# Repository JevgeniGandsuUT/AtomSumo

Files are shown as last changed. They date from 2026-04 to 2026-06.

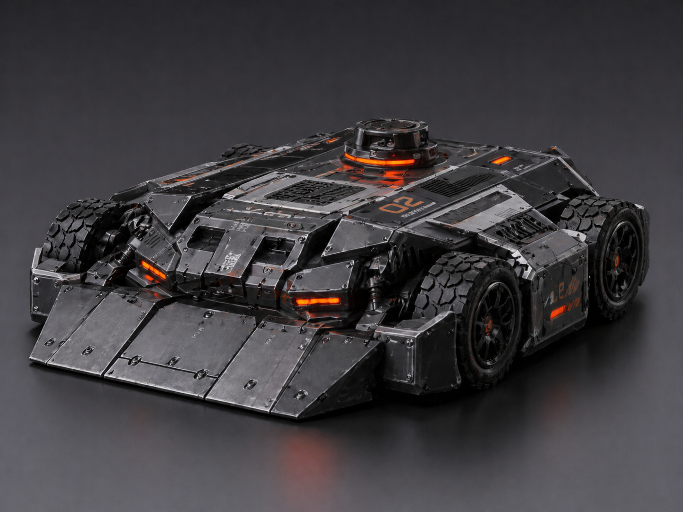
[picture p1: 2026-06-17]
hardware/cad/ver3/Concept.png

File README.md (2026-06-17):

# ATOM Sumo

`ATOM Sumo` is a SMARS-inspired sumo robot prototype for the University of Tartu prototyping course.

The project combines:
- an `M5 ATOM` main controller;
- `2 x M5 AtomS3R-CAM` camera nodes;
- `2S 18650` battery power;
- `TB6612FNG` motor driver;
- `4 x N20 6V` drive motors, wired as left/right parallel motor pairs;
- `VL53L0X` front ToF distance sensing;
- `TCS34725` floor color telemetry on Cam 2;
- a browser-based control interface over the robot's own Wi-Fi access point.

The long-term goal is one reliable working prototype plus enough documentation to support small-batch replication before the arena event.

## Current architecture

- Main controller firmware: [`firmware/main/main.ino`](firmware/main/main.ino)
- Camera firmware: [`firmware/camera/sketch_jan17a/sketch_jan17a.ino`](firmware/camera/sketch_jan17a/sketch_jan17a.ino)
- Documentation index: [`docs/README.md`](docs/README.md)
- Power concept: [`docs/specification/power_scheme.md`](docs/specification/power_scheme.md)
- Electrical block diagram: [`hardware/diagrams/power_tree.drawio`](hardware/diagrams/power_tree.drawio)
- System block diagram: [`hardware/diagrams/system_block.drawio`](hardware/diagrams/system_block.drawio)
- PCB package: [`hardware/pcb/README.md`](hardware/pcb/README.md)
- Formal V1 specification: [`docs/specification/V1_specification.md`](docs/specification/V1_specification.md)
- Requirements tracker Excel: [`docs/milestones/VERSTAPOST_REQUIREMENTS_TRACKER.xlsx`](docs/milestones/VERSTAPOST_REQUIREMENTS_TRACKER.xlsx)
- Technical comparison: [`docs/specification/TECH_COMPARISON.md`](docs/specification/TECH_COMPARISON.md)
- Estonian comparative analysis: [`docs/analysis/Vordlev_analyys.docx`](docs/analysis/Vordlev_analyys.docx), [`docs/analysis/Vordlev_analyys_summary.md`](docs/analysis/Vordlev_analyys_summary.md)
- Full test-results notebook: [`tests/notebooks/test_results_analysis.ipynb`](tests/notebooks/test_results_analysis.ipynb)
- Notebook launcher: [`tools/RUN_TEST_RESULTS_NOTEBOOK.ps1`](tools/RUN_TEST_RESULTS_NOTEBOOK.ps1)
- Original Verstapost brief images: [`docs/assets/briefs`](docs/assets/briefs)

Current hardware baseline:
- differential `4WD` drive with `2` motors wired in parallel on each side;
- `6.0V` motor rail for `4 x N20 6V` motors;
- separate `5.0V` logic rail for controller, cameras, and sensors;
- robot Wi-Fi AP `Robot-Control` with browser control UI.

Reference build components:

| Component | Quantity | Role / current status |
| --- | ---: | --- |
| `M5 ATOM` main controller | 1 | Main ESP32 controller for Wi-Fi AP, web UI, motor control, ToF, and robot state |
| `M5 AtomS3R-CAM` | 2 | Cam 1 front/operator stream and Cam 2 upward/downward diagnostic/color node |
| `VL53L0X` ToF module | 1 | Front distance sensing over I2C |
| `TCS34725` / `CJMCU-34725` RGB color sensor | 1 used / 2 ordered | Floor color telemetry on Cam 2 Grove I2C |
| `TB6612FNG` dual motor driver | 1 | Two-channel drive; left motor pair on channel A and right motor pair on channel B |
| `N20 6V` DC gearmotor | 4 | Four-wheel drive, two motors wired in parallel per side |
| Driven wheel pair `42 x 19 mm` | 2 pairs | Four driven wheels total |
| `2 x 18650` Li-Ion cells | 2 | Main `2S` battery pack |
| `2x18650` battery holder | 1 | Battery mount for the reference build |
| `2S 3A` BMS/protection board | 1 | Battery protection, still requires high-load validation |
| `1-2S` Li-Ion charger module | 1 | Charging path for the 2S pack |
| USB-C PD trigger module | 1 | Bench/charging input source used in the power setup |
| DC-DC step-down module `5A` | 2 | One set to `5.0V` logic rail, one set to `6.0V` motor rail |
| `1000uF / 16V` capacitor | 1 | Motor rail bulk decoupling near the driver |
| Slide switch | 1 | Master power switch |
| Custom PCB / interconnect board | 1 design | EasyEDA/Gerber evidence present; latest Gerber package is included |
| 3D-printed chassis/enclosure | 1 set | CAD and photo evidence present; final heat/impact/service validation still open |

## Current status

Already available in the repository:
- working main control sketch with AP mode and web control UI;
- working `AtomS3R-CAM` streaming sketch;
- V1 specification and BOM;
- power tree and PCB artifacts;
- latency, movement, ToF, and brownout measurements with executed analysis notebooks;
- CAD for the baseline chassis, functional enclosure, and real Fusion 360 robot assembly.

Important current limitation:
- final enclosure/endurance validation is still pending; the robot has movement CSVs, but heat, impact, battery-service, and repeated match-like tests still need measured tables.

## Submission tracker

The main submission document is:

- [`docs/milestones/VERSTAPOST_REQUIREMENTS_TRACKER.xlsx`](docs/milestones/VERSTAPOST_REQUIREMENTS_TRACKER.xlsx)

It lists all Verstapost 1-5 requirements in order, marks whether each item is complete, and links to the evidence files.

## Key results

HTTP control latency measurements are stored in [`tests/results`](tests/results).

Most useful current runs:
- before motor A fix: [`http_latency_2026-04-11_18-28-33.csv`](tests/results/http_latency_2026-04-11_18-28-33.csv)
- after motor A fix at `speed=0`: [`http_latency_2026-04-11_19-34-31.csv`](tests/results/http_latency_2026-04-11_19-34-31.csv)
- after fix at `speed=180`: [`http_latency_2026-04-11_19-38-18_medium_speed.csv`](tests/results/http_latency_2026-04-11_19-38-18_medium_speed.csv)

Summary:
- `speed=0` after fix: median `31.538 ms`, p95 `53.042 ms`, max `68.883 ms`
- `speed=180`: median `87.373 ms`, p95 `158.018 ms`, max `186.038 ms`

Detailed write-up:
- [`docs/testing/latency_test_result.md`](docs/testing/latency_test_result.md)
- [`tests/notebooks/http_latency_analysis.ipynb`](tests/notebooks/http_latency_analysis.ipynb)
- [`tests/notebooks/test_results_analysis.ipynb`](tests/notebooks/test_results_analysis.ipynb)

## Milestone evidence

Detailed evidence is linked from the Excel tracker and from the documentation index. The most important supporting areas are:

- [`docs/specification`](docs/specification) - specification, BOM, power scheme, and comparison analysis.
- [`docs/testing`](docs/testing) - test plan and test protocols.
- [`tests/results`](tests/results) - CSV measurement data.
- [`tests/notebooks`](tests/notebooks) - analysis notebooks.
- [`firmware`](firmware) - main controller and camera firmware.
- [`hardware`](hardware) - CAD, PCB, and diagrams.

## Repository structure

### Firmware

- [`firmware/main/`](firmware/main)  
  Main robot controller firmware: Wi-Fi AP, web UI, motor control, speed control, command handling.

- [`firmware/camera/`](firmware/camera)  
  Firmware for the `M5 AtomS3R-CAM` nodes that provide MJPEG video streams.

### Tools

- [`tools/`](tools)  
  Double-click PowerShell launchers for measurement runs and notebook regeneration.

### Documentation

- [`docs/README.md`](docs/README.md)  
  Documentation index and fastest way into the Excel tracker and evidence files.

- [`docs/specification/`](docs/specification)  
  System specification, BOM, power scheme, and technical comparison.

- [`docs/guides/`](docs/guides)  
  Assembly, flashing, and print-setting guides.

- [`docs/testing/`](docs/testing)  
  Test plan, movement/sensor protocol, and latency write-up.

- [`docs/milestones/`](docs/milestones)  
  Main Excel tracker and milestone status.

- [`docs/assets/`](docs/assets)  
  Milestone brief images, order screenshots, and photo evidence.

### Tests and measurements

- [`tests/README.md`](tests/README.md)  
  Index for executable tests, measurement CSV files, and notebooks.

- [`tests/scripts/`](tests/scripts)  
  Python scripts used to collect latency, brownout, and ToF accuracy data.

- [`tests/notebooks/`](tests/notebooks)  
  Jupyter notebooks with tables, graphs, and interpretation.

- [`tests/results/`](tests/results)  
  Raw CSV files and summary text files from executed tests.

### Electronics and diagrams

- [`hardware/diagrams/power_tree.drawio`](hardware/diagrams/power_tree.drawio)  
  Editable draw.io electrical block diagram.

- [`hardware/diagrams/system_block.drawio`](hardware/diagrams/system_block.drawio)  
  Editable top-level system architecture diagram.

- [`hardware/pcb/`](hardware/pcb)  
  PCB screenshots, schematic/layout source exports, 3D view, and Gerber archives. Start with [`hardware/pcb/README.md`](hardware/pcb/README.md).

### Mechanical

- [`hardware/cad/ver1/chassis_n20.scad`](hardware/cad/ver1/chassis_n20.scad)  
  Parametric OpenSCAD chassis model.

- [`hardware/cad/ver1/chassis_n20.stl`](hardware/cad/ver1/chassis_n20.stl)  
  Exported printable chassis geometry.

- [`hardware/cad/ver3/`](hardware/cad/ver3)  
  Functional enclosure/body models and rendered views.

- [`hardware/cad/real/`](hardware/cad/real)  
  Real Fusion 360 robot assembly and parts, including body, shell, top cover, battery pack, wheels, N20 motor reference, PCB body, and M5 Atom placement.

### Media

- [`docs/assets/photos/README.md`](docs/assets/photos/README.md)
  Photo evidence for fabrication, electronics integration, printed enclosure parts, and assembled robot state.

- [`media/video/README.md`](media/video/README.md)
  Index of video evidence with measured durations.

- [`media/video/MicrosoftTeams-video.mp4`](media/video/MicrosoftTeams-video.mp4)  
  Demo evidence showing camera streaming.

- [`media/video/0-02-05-5cafa7a371385dc5dc37026175887d8e437ea1f9ac49a73fc301792a9de68af1_9c676645fed6c17c.mp4`](media/video/0-02-05-5cafa7a371385dc5dc37026175887d8e437ea1f9ac49a73fc301792a9de68af1_9c676645fed6c17c.mp4)
  Additional robot/camera demonstration video evidence.

## Recommended reading order

If you are opening this repository for the first time, start here:

1. [`docs/specification/V1_specification.md`](docs/specification/V1_specification.md)
2. [`docs/milestones/VERSTAPOST_REQUIREMENTS_TRACKER.xlsx`](docs/milestones/VERSTAPOST_REQUIREMENTS_TRACKER.xlsx)
3. [`docs/specification/TECH_COMPARISON.md`](docs/specification/TECH_COMPARISON.md)
4. [`docs/testing/test_plan.md`](docs/testing/test_plan.md)
5. [`docs/specification/BOM.csv`](docs/specification/BOM.csv)
6. [`docs/specification/power_scheme.md`](docs/specification/power_scheme.md)
7. [`docs/testing/test_plan.md`](docs/testing/test_plan.md)
8. [`firmware/main/main.ino`](firmware/main/main.ino)
9. [`firmware/camera/sketch_jan17a/sketch_jan17a.ino`](firmware/camera/sketch_jan17a/sketch_jan17a.ino)
10. [`tests/notebooks/http_latency_analysis.ipynb`](tests/notebooks/http_latency_analysis.ipynb)

## Next project steps

Planned next technical steps:
- calibrate or explain the measured `VL53L0X` offset;
- run the full auto-behavior logger test after charging the robot;
- complete enclosure heat/impact/service/endurance tests;
- add final multi-angle assembly photos and measured validation tables.

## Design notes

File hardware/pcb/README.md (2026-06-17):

# PCB Package

This folder contains the schematic, PCB layout, 3D view, Gerber archives, and EasyEDA-style JSON source files for the ATOM Sumo interconnect board.

## Latest PCB Evidence

- [PCB_EVIDENCE_CHECK.md](PCB_EVIDENCE_CHECK.md) - current PCB evidence checklist and optional production-readiness DRC/export screenshot gap.
- [Schematic_ATOM-Sumo_2026-06-13.png](Schematic_ATOM-Sumo_2026-06-13.png) - latest schematic screenshot.
- [SCH_ATOM-Sumo_2026-06-13.json](SCH_ATOM-Sumo_2026-06-13.json) - latest schematic source export.
- [PCB_PCB_ATOM_SUMO_2026-06-13.png](PCB_PCB_ATOM_SUMO_2026-06-13.png) - latest PCB layout screenshot.
- [PCB_PCB_ATOM_SUMO_2026-06-13.json](PCB_PCB_ATOM_SUMO_2026-06-13.json) - latest PCB layout source export.
- [PCB_extra_screenshot_2026-06-13_235021.png](PCB_extra_screenshot_2026-06-13_235021.png) - additional PCB evidence screenshot.
- [3d.png](3d.png) - PCB 3D view screenshot.
- [Gerber_ATOM-Sumo_PCB_ATOM_SUMO_2026-06-17.zip](Gerber_ATOM-Sumo_PCB_ATOM_SUMO_2026-06-17.zip) - latest manufacturing Gerber/drill export.

## Previous PCB Evidence

- [Schematic_ATOM-Sumo_2026-04-11.png](Schematic_ATOM-Sumo_2026-04-11.png) - earlier schematic screenshot.
- [PCB_PCB_ATOM_SUMO_2026-04-11.png](PCB_PCB_ATOM_SUMO_2026-04-11.png) - earlier PCB layout screenshot.
- [Gerber_ATOM-Sumo_PCB_ATOM_SUMO_2026-04-08.zip](Gerber_ATOM-Sumo_PCB_ATOM_SUMO_2026-04-08.zip) - earlier Gerber package.
- [Gerber_ATOM-Sumo_PCB_ATOM_SUMO_2026-04-08-2.zip](Gerber_ATOM-Sumo_PCB_ATOM_SUMO_2026-04-08-2.zip) - source/export package.

## Submission Note

For the final milestone package, the `2026-06-13` schematic/PCB JSON/PNG files and the `2026-06-17` Gerber export are the current PCB evidence. The April files are kept as older traceability and Gerber/export history.

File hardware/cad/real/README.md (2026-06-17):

# Real CAD Package

This folder contains the real Fusion 360 CAD files for the robot mechanical package and related components.

## Main Assemblies

- [Robot.f3d](<Robot.f3d>) - robot-level Fusion design.
- [Assembly new.f3z](<Assembly new.f3z>) - packed Fusion assembly archive.
- [Rawproto.f3z](<Rawproto.f3z>) - raw prototype assembly archive.

## Robot Body Parts

- [Base 1.f3d](<Base 1.f3d>) - base body part.
- [Shell.f3d](<Shell.f3d>) - outer shell/body.
- [Topcover.f3d](<Topcover.f3d>) - top cover.
- [Battery pack.f3d](<Battery pack.f3d>) - battery pack/body integration.
- [PCB body.f3d](<PCB body.f3d>) - PCB body/holder geometry.
- [Floor.f3d](<Floor.f3d>) - arena or floor reference model.

## Drive and Hardware Parts

- [Wheel.f3d](<Wheel.f3d>) - wheel model.
- [wheel 43mm.f3d](<wheel 43mm.f3d>) - 43 mm wheel model.
- [Rear axcel.f3d](<Rear axcel.f3d>) - rear axle part.
- [N20 Reduction Gear Motor - LA002 LA003 LA004.f3d](<N20 Reduction Gear Motor - LA002 LA003 LA004.f3d>) - N20 motor model.
- [M5 ATOM Lite.f3d](<M5 ATOM Lite.f3d>) - M5 Atom controller model.

## External and Iteration Files

- [External1.f3d](<External1.f3d>)
- [External2.f3d](<External2.f3d>)
- [External3.f3d](<External3.f3d>)
- [External4.f3d](<External4.f3d>)
- [External5.f3d](<External5.f3d>)
- [3rdfloor.f3d](<3rdfloor.f3d>)
- [3D_1-PCB_PCB_ATOM_SUMO_2026-04-14.f3d](<3D_1-PCB_PCB_ATOM_SUMO_2026-04-14.f3d>)
- [a50.f3d](<a50.f3d>)
- [Cilinder.f3d](<Cilinder.f3d>)
- [Katus.f3d](<Katus.f3d>)
- [ksr_fdmtest_v4.f3d](<ksr_fdmtest_v4.f3d>)

## Submission Note

For Verstapost 4 and 5 this folder should be treated as the strongest mechanical evidence, because it contains real Fusion 360 source files for the assembled robot, body, wheels, motor reference, battery packaging, PCB holder, and controller placement.

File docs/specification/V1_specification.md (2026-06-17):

# V1 System Specification

## Document Control

| Field | Value |
| --- | --- |
| Project | SMARS-inspired Sumo Robot |
| Internal name | ATOM Sumo |
| Version | 1.0 |
| Date | 2026-04-11 |
| Status | Ready for Verstapost 1 review |
| Primary architecture | M5 ATOM main controller + 2 x M5 AtomS3R-CAM + 2S 18650 power system + 4 x N20 6V drive motors |

## 1. Purpose and Scope

This document defines the baseline system specification for a compact sumo robot intended for the University of Tartu prototyping course. The specification is written so that another team could reproduce the reference robot architecture, understand the current design decisions, and continue development through Verstapost 2-5.

The reference design standardizes on:

- an M5 ATOM controller as the robot's main brain;
- two M5 AtomS3R-CAM modules as network cameras;
- a `2S 18650` battery pack as the main energy source;
- differential 4WD drive with four N20 6V DC gearmotors, wired as two left/right parallel motor pairs;
- a browser-based operator interface over the robot's own Wi-Fi network.

This document describes the target system behavior, the current implementation baseline already present in the repository, and the required validation work still needed before full arena deployment.

## 2. Repository Baseline

The current specification is grounded in the following repository artifacts:

- [firmware/main/main.ino](../../firmware/main/main.ino)
- [firmware/camera/sketch_jan17a/sketch_jan17a.ino](../../firmware/camera/sketch_jan17a/sketch_jan17a.ino)
- [hardware/cad/ver1/chassis_n20.scad](../../hardware/cad/ver1/chassis_n20.scad)
- [hardware/cad/ver1/chassis_n20.stl](../../hardware/cad/ver1/chassis_n20.stl)
- [hardware/pcb/Gerber_ATOM-Sumo_PCB_ATOM_SUMO_2026-04-08.zip](../../hardware/pcb/Gerber_ATOM-Sumo_PCB_ATOM_SUMO_2026-04-08.zip)
- [hardware/pcb/Gerber_ATOM-Sumo_PCB_ATOM_SUMO_2026-04-08-2.zip](../../hardware/pcb/Gerber_ATOM-Sumo_PCB_ATOM_SUMO_2026-04-08-2.zip)
- [media/video/MicrosoftTeams-video.mp4](../../media/video/MicrosoftTeams-video.mp4)
- [docs/assets/briefs/Versta1.png](../assets/briefs/Versta1.png)

Observed baseline from those files:

- the main controller already creates Wi-Fi AP `Robot-Control`;
- the browser UI already supports manual drive and speed control;
- the UI already embeds two camera streams at `192.168.4.20` and `192.168.4.21`;
- the camera firmware already serves `/stream` and `/capture`;
- the CAD model already reserves space for front camera, downward camera, ToF window, PCB area, and a DC/DC converter;
- PCB Gerber and EasyEDA source files already exist.
- a recorded video artifact in `media/video/MicrosoftTeams-video.mp4` provides practical confirmation that streaming was demonstrated; the file is approximately `32 s` long.
- the original Verstapost 1 assignment/reference image is stored in `docs/assets/briefs/Versta1.png` so the repository keeps the submitted specification aligned with the course milestone brief.

## 3. System Overview

### 3.1 Mission

The robot shall operate inside a `3000 x 3000 mm` arena assembled from `1000 x 1000 mm` OSB modules with a `100 mm` hole grid, colored surface inserts, and `100 mm` high perimeter walls. The robot shall support both operator-controlled and semi-autonomous sumo behavior.

### 3.2 Top-Level Functions

The system shall:

- move using differential drive;
- stream live video to a browser UI;
- measure front obstacle distance;
- detect arena surface and boundary conditions;
- estimate robot position on the arena at least coarsely;
- accept manual drive commands and later click-to-drive commands;
- run from an onboard rechargeable `2S 18650` battery pack.

### 3.3 Selected Architecture

The selected architecture is a practical refinement of course Variant B:

- main controller: M5 ATOM module;
- front operator camera: M5 AtomS3R-CAM;
- downward arena camera: M5 AtomS3R-CAM;
- front distance sensor: `VL53L0X` ToF over `I2C`;
- motor driver: dual `TB6612FNG`;
- power system: `2S 18650` pack with charger, BMS, master switch, and separate logic and motor regulators.

This choice is based on the actual code and CAD already present in the repository.

### 3.4 Deviation from the Original Variant B Brief

The original Verstapost 1 sumo-robot brief proposes an older Android phone as the main robot brain. The reference build in this repository intentionally moves the embedded robot brain to an M5 ATOM / ESP32 controller and uses phones or laptops as browser clients only.

This deviation is acceptable for the selected prototype because it preserves the required system functions while reducing integration risk:

- the robot still provides remote operator control through a phone browser;
- the robot still has front vision through an `AtomS3R-CAM`;
- the robot still has downward sensing for floor color and future positioning;
- the robot still uses an ESP32-class controller for motor-driver interfacing;
- the control and camera firmware already exist and have been tested in the repository.

The Android-phone path remains a possible later UI/client option, but it is not required as the onboard compute platform for this reference build.

## 4. Operating Environment and Constraints

### 4.1 Arena

The robot is designed for the course arena with the following properties:

- arena size: `3000 x 3000 mm`;
- module size: `1000 x 1000 mm`;
- hole pitch: `100 mm`;
- hole diameter: `5 mm`;
- surface: OSB with removable colored inserts no higher than `2 mm` above the floor;
- wall height: `100 mm`.

### 4.2 Project Constraints

- total robot budget target: `<= 300 EUR`;
- build shall be reproducible using off-the-shelf parts plus 3D-printed parts;
- system shall be documented inside the repository;
- the V1-V2 baseline may use wheels for rapid iteration, but the motor and chassis layout shall remain compatible with a later SMARS-style tracked revision if that becomes advantageous.

### 4.3 Assumptions

- The M5 ATOM main controller and the two M5 AtomS3R-CAM boards are assumed to be available, because working firmware for them already exists in the repository.
- The exact motor gearbox ratio is not yet frozen and shall be confirmed through motor sizing and push testing, but the motor voltage class is fixed at `6V`.
- The baseline OpenSCAD CAD contains an older powerbank-style bay, while the real Fusion 360 CAD package now includes battery-pack models. The final physical tray still needs print and service-access validation.

## 5. Functional Requirements

The following functional requirements are prioritized using the `MoSCoW` method.

| ID | Requirement | Priority | Verification |
| --- | --- | --- | --- |
| FR-01 | The robot shall create its own Wi-Fi access point and allow the operator to connect without an external router. | Must | Bench test |
| FR-02 | The operator shall control the robot from a browser-based web UI running on a phone or laptop. | Must | Bench test |
| FR-03 | The web UI shall provide `forward`, `backward`, `left`, `right`, `stop`, and speed control. | Must | Bench test |
| FR-04 | The system shall provide a live front camera stream for operator vision. | Must | Bench test |
| FR-05 | The system shall provide a live downward-facing camera stream for arena observation, calibration, and positioning. | Must | Bench test |
| FR-06 | The robot shall use differential drive with two independently controlled motor channels; each channel may drive a left/right pair of parallel motors. | Must | Bench test |
| FR-07 | The robot shall measure forward obstacle distance using a `VL53L0X` ToF sensor over `I2C`. | Must | Bench test |
| FR-08 | The robot shall be powered by an onboard `2S 18650` battery pack with charging and protection circuitry. | Must | Bench test |
| FR-09 | The power system shall provide separated logic and motor supply rails with a common ground. | Must | Bench and wiring inspection |
| FR-10 | The robot shall detect arena boundary or unsafe floor state and command a stop or retreat. | Must | Arena test |
| FR-11 | The operator UI shall display basic robot state, including at minimum connection status, speed setting, and camera availability; later revisions shall add battery, ToF, and boundary state. | Should | UI test |
| FR-12 | The robot shall estimate coarse arena pose using the downward camera and arena visual features such as colored inserts, grid geometry, or fixed markers. | Should | Arena test |
| FR-13 | The operator shall be able to click a point in the front camera image and command the robot to drive toward the corresponding ground-plane target. | Should | Arena test |
| FR-14 | The robot shall support both manual mode and autonomous sumo mode. | Should | Integration test |
| FR-15 | The system should log latency, distance, and battery data during development tests. | Could | Data logging test |
| FR-16 | The system could expose a machine-readable telemetry endpoint for notebooks and automated tests. | Could | API test |
| FR-17 | The system will not depend on an Android phone as the main compute platform in this reference design. | Won't | Design review |
| FR-18 | The V1-V2 baseline will not require UWB localization hardware. | Won't | Design review |

## 6. Performance Targets

The following are target values for the reference prototype. They are engineering targets, not yet measured acceptance results.

| Parameter | Target | Notes |
| --- | --- | --- |
| Maximum body footprint | `<= 150 x 150 mm` | Current CAD body is `150 x 108 mm` |
| Minimum ground clearance | `>= 10 mm` | From CAD target |
| Nominal top speed | `0.4-0.6 m/s` | To cross the arena quickly while remaining controllable |
| 180 degree turn-in-place time | `<= 1.2 s` | At nominal `6.0V` motor rail |
| Push force at wheels | `>= 4 N` target | Final value to be validated with sled test |
| Manual command latency | median `<= 100 ms`, p95 `<= 150 ms` | Button press to observed motor response |
| Camera stream rate | `>= 10 fps` at `QVGA` | Existing camera firmware already targets streaming |
| Boot to usable control page | `<= 20 s` | Power-on to reachable web UI |
| Active runtime | `>= 15 min` or `>= 5` matches of `3 min` with reserve | Based on `2S 2500 mAh` pack |
| Boundary stop distance | `< 100 mm` worst case | Must remain inside 100 mm warning zone |
| Click-to-drive position error | `<= 150 mm` at `0.5 m`, `<= 250 mm` at `1.0 m` | Target for V3 |
| Front distance sensing range | `50 mm` to `2 m` practical target | Final practical limit depends on target material |

## 7. Mechanical Specification

### 7.1 Chassis Concept

The robot uses a compact monocoque-style 3D-printed chassis modeled in OpenSCAD.

Baseline geometry from the current CAD:

- body length: `150 mm`;
- body width: `108 mm`;
- hull height: `34 mm`;
- ground clearance target: `10 mm`;
- PCB inner area: `60.5 x 60.5 mm`;
- motor cavity designed around `N20 6V` motors;
- front wedge/scoop for pushing;
- dedicated apertures for front camera, downward camera, and ToF sensor.

### 7.2 Drive Train

The reference drive train is:

- 4 x `N20 6V` DC gearmotors (`N20` class footprint assumed by CAD);
- two-channel differential steering;
- 4 wheels total in the V1-V2 wheel baseline;
- 4 x `42 x 19 mm` wheels used as driven wheels;
- two left-side motors wired in parallel to one TB6612 channel;
- two right-side motors wired in parallel to the other TB6612 channel.

The wheel layout therefore uses:

- one left and one right driven wheel pair for propulsion and turning;
- skid/differential steering controlled by the two TB6612 channels.

The current wiring uses parallel motor pairs per side, so current draw and driver heating must be validated before high-load pushing tests.

The wheel-based baseline is acceptable for early prototyping because it accelerates testing of:

- motor selection;
- current draw;
- driver behavior;
- web control latency;
- battery performance.

The drive architecture intentionally preserves the option to replace the wheel module with SMARS-style tracks later without changing the top-level electrical or software architecture.

### 7.3 Camera and Sensor Placement

- Front camera: mounted in the front upper shell and used for operator vision and click-to-drive projection.
- Downward camera: mounted near the front underside and used for floor observation, color/boundary detection, and coarse positioning.
- ToF sensor: mounted in the front shell in a separate window offset from the front camera.

### 7.4 Battery Packaging Revision

The baseline OpenSCAD CAD still contains a `powerbank bay`. The newer real Fusion 360 CAD package includes battery-pack models, but the final physical `2S 18650` architecture shall still be validated as:

- a `2 x 18650` holder or custom printed battery tray;
- a protected and serviceable battery mount;
- easy access for cell replacement and wiring inspection;
- placement that keeps the center of mass low and near the driven axle.

## 8. Electrical Specification

### 8.1 Power Tree

The reference power tree is:

```text
USB-C PD Trigger (12 V input source during charging/setup)
    -> 1-2S Li-Ion charger module
    -> 2S 18650 pack
    -> 2S BMS / protection module
    -> master power switch
        -> Buck regulator #1 -> 5.0 V logic rail
        -> Buck regulator #2 -> 6.0 V motor rail
```

Logic rail consumers:

- M5 ATOM main controller;
- 2 x M5 AtomS3R-CAM;
- `VL53L0X`;
- future low-power sensors and status LEDs.

Motor rail consumers:

- `TB6612FNG` VM input on `6.0V` motor rail;
- left and right `N20 6V` motor pairs.

### 8.2 Power Design Requirements

- All modules shall share a common electrical ground.
- Logic and motor rails shall be separately regulated to reduce brownouts and motor noise coupling.
- A bulk capacitor of approximately `1000 uF / 16 V` shall be placed near the motor driver supply.
- The logic rail shall be fixed at `5.0V`.
- The motor rail shall be fixed at `6.0V` for the selected `N20 6V` motors.
- Raw `8.4 V` from a fully charged `2S` pack shall not be applied directly to the `N20 6V` motors.

### 8.3 Main Controller Pin Mapping

The current firmware defines the following control pins:

| Signal | Pin |
| --- | --- |
| `PWMA` | `22` |
| `AIN1` | `19` |
| `AIN2` | `23` |
| `PWMB` | `25` |
| `BIN1` | `21` |
| `BIN2` | `33` |
| `ATOM_LED_PIN` | `27` |

These pins are already used by the main controller firmware in [firmware/main/main.ino](../../firmware/main/main.ino).

### 8.4 Camera Networking

The current camera firmware uses the following network assignments:

| Device | Mode | Address |
| --- | --- | --- |
| Main controller | Wi-Fi AP | `192.168.4.1` |
| Front camera node | Wi-Fi STA | `192.168.4.20` |
| Downward camera node | Wi-Fi STA | `192.168.4.21` |

The reference SSID in current firmware is `Robot-Control`.

### 8.5 ToF Interface

The front distance sensor shall be a `VL53L0X` connected via `I2C`. Required outputs:

- filtered distance value in millimeters;
- validity or timeout status;
- update rate sufficient for obstacle avoidance and telemetry.

## 9. Software Architecture

### 9.1 Main Controller Firmware

The main controller firmware is responsible for:

- creating the robot Wi-Fi access point;
- serving the operator web UI;
- receiving manual drive commands;
- setting motor direction and PWM;
- exposing speed control;
- integrating future telemetry and sensor endpoints;
- later managing mode switching between manual and autonomous behavior.

Current implemented HTTP endpoints in the repository:

- `GET /` -> control UI;
- `GET /move?dir=forward|backward|left|right|stop`;
- `GET /speed?value=0..255`.

### 9.2 Camera Node Firmware

Each M5 AtomS3R-CAM node is responsible for:

- connecting to the main controller access point;
- serving an MJPEG stream over HTTP;
- serving single snapshot capture on request.

Current camera endpoints in the repository:

- `GET /` -> simple camera page;
- `GET /stream` -> MJPEG stream;
- `GET /capture` -> single JPEG frame.

### 9.3 Operator Web UI

The web UI shall support:

- mobile-friendly and laptop-friendly layout;
- low-friction connection to the robot AP;
- live front camera video;
- live downward camera video or diagnostic view;
- manual directional control;
- stop command;
- speed adjustment slider;
- future mode selection and state display.

### 9.4 Planned Control Modes

The software shall evolve toward the following modes:

- `Manual`: direct operator commands;
- `Click-to-drive`: operator selects a ground target in the image and the robot executes rotate-and-drive;
- `Autonomous`: robot uses ToF and arena sensing to attack and avoid leaving the arena.

## 10. Positioning and Click-to-Drive Specification

### 10.1 Positioning System

The reference design uses the downward-facing camera as the primary positioning sensor.

The downward camera shall estimate coarse robot position and floor state using one or more of:

- arena hole-grid geometry at `100 mm` spacing;
- colored arena inserts;
- fixed printed markers placed on the arena surface or perimeter.

The design intentionally keeps the exact visual marker scheme flexible so that the team can calibrate what works best in the real arena without changing the robot hardware.

### 10.2 Click-to-Drive Logic

The click-to-drive pipeline shall be:

1. The operator clicks a point in the front camera image.
2. The system maps the pixel to a camera ray using calibrated intrinsics.
3. The ray is intersected with the arena ground plane using measured camera height and mounting angle.
4. The ground-plane target is transformed into robot-local coordinates.
5. The robot first rotates toward the target, then drives forward, then stops or corrects based on ToF and floor sensing.

### 10.3 Required Calibration Data

The following values shall be measured and stored:

- front camera focal parameters or calibrated projection model;
- front camera height above ground;
- front camera pitch relative to the ground plane;
- robot center reference point used in accuracy measurements.

### 10.4 Safety Limits for Click-to-Drive

The click-to-drive controller shall reject:

- clicks outside the valid ground region of the camera image;
- targets beyond the configured maximum ground distance;
- targets that intersect known arena boundaries or walls.

## 11. Communication and Data Interface Specification

### 11.1 Network

| Parameter | Value |
| --- | --- |
| Wi-Fi mode | Main controller as AP, camera nodes as STA |
| Reference SSID | `Robot-Control` |
| Security | WPA2 PSK |
| Reference password | stored in firmware and changeable in release builds |

### 11.2 Control API

Current control API baseline:

| Endpoint | Method | Purpose |
| --- | --- | --- |
| `/` | `GET` | Serve control page |
| `/move?dir=...` | `GET` | Direction command |
| `/speed?value=...` | `GET` | Speed setting |

Target telemetry API for later revisions:

| Endpoint | Method | Purpose |
| --- | --- | --- |
| `/state` | `GET` | Return robot telemetry as JSON |
| `/mode` | `POST` or `GET` | Change manual/autonomous mode |
| `/target` | `POST` | Submit click-to-drive target |

Target `/state` JSON fields:

```json
{
  "mode": "manual",
  "speed_pwm": 180,
  "tof_mm": 235,
  "boundary": false,
  "battery_v": 7.6,
  "cam_front": true,
  "cam_down": true
}
```

## 12. Safety, Fault Handling, and Serviceability

The robot shall be designed so that:

- a stop command is always available from the UI;
- the motors default to stop on controller reset;
- the power system includes battery protection;
- camera loss does not cause uncontrolled motion;
- future revisions add command timeout or heartbeat stop behavior;
- the battery is accessible for service between matches;
- wiring is restrained against pull-out during impacts.

Known risk items that must be validated:

- the ordered `2S 3A` BMS may be too weak for motor surge current;
- the exact motor gearbox ratio is not yet frozen and must still be validated by testing;
- the final CAD battery packaging must be validated physically for `18650` service access;
- boundary/color telemetry exists, but closed-loop arena behavior is not yet completed.

## 13. Verification and Test Plan

Each functional requirement shall be verified using one or more of the following methods:

- `Bench test`: stationary electrical or software test on the workbench;
- `Drive test`: flat-floor motion test;
- `Arena test`: test inside the real or mock arena;
- `Inspection`: visual inspection of hardware or CAD;
- `Data analysis`: logged measurements analyzed in a notebook.

### 13.1 Verification Matrix

| Requirement | Planned verification |
| --- | --- |
| FR-01 | Power on the robot and confirm AP visibility and successful client connection |
| FR-02 | Open the browser UI from a phone and a laptop without installing an app |
| FR-03 | Command all directions and verify immediate motor response and stop behavior |
| FR-04 | Confirm front video stream is visible and stable for at least 2 minutes |
| FR-05 | Confirm downward camera stream is visible and aligned to the floor view |
| FR-06 | Run forward, reverse, and turn tests on a flat surface |
| FR-07 | Measure ToF readings at fixed distances such as 5, 10, 20, 30, and 50 cm |
| FR-08 | Run robot from `2S 18650` pack and confirm charging path and protected discharge path |
| FR-09 | Verify separate regulated rails and absence of controller resets during motor start/stop |
| FR-10 | Approach the arena boundary ten times and measure successful stop/retreat rate |
| FR-11 | Confirm state indicators render in the UI and update during operation |
| FR-12 | Measure coarse pose estimate against the arena grid at multiple locations |
| FR-13 | Run click-to-drive to at least five target points and measure position error |
| FR-14 | Demonstrate manual mode and autonomous mode switching |
| FR-15 | Record latency and power measurements to CSV or notebook |
| FR-16 | Query telemetry endpoint and validate field format |
| FR-17 | Design review: confirm no Android phone is required in the reference build |
| FR-18 | Design review: confirm no UWB hardware is required in the reference build |

### 13.2 Priority Acceptance Tests for V2

The most important near-term tests are:

1. Motor drive test: forward, reverse, turn, stop, current draw, and push force.
2. Wi-Fi latency test: `100+` repeated command-response measurements.
3. Camera stability test: continuous streaming over the robot AP.
4. Power test: startup, brownout resistance, and runtime using `2S 18650`.
5. ToF accuracy test: repeated measurements at known distances.

## 14. Preliminary BOM and Procurement Status

The table below reflects the currently chosen architecture for one working reference build. Where a component is not shown in the order screenshots but is clearly implied by the repository, it is marked as assumed available.

| Item | Qty | Status | Approx. cost | Notes |
| --- | --- | --- | --- | --- |
| M5 ATOM main controller | 1 | assumed available | existing stock / not counted | Working firmware already exists in repo |
| M5 AtomS3R-CAM | 2 | assumed available | existing stock / not counted | Working camera firmware already exists in repo |
| `VL53L0X` ToF module | 1 | ordered | `9.50 EUR` | Front distance sensing |
| SparkFun `TB6612FNG` dual motor driver | 1 | ordered | `13.36 EUR` | Main dual motor driver |
| USB-C PD trigger module `12 V` | 1 | ordered | `4.28 EUR` | Charging/setup source path |
| `1-2S` Li-Ion charger module | 1 | ordered | `4.28 EUR` | Charging path |
| `2x18650` battery holder | 1 | ordered | `2.38 EUR` | Needs CAD integration |
| `2S 3A` BMS/protection board | 1 | ordered | `2.85 EUR` | Must be surge-tested |
| DC/DC step-down module `5 A` | 2 | ordered | `22.80 EUR` total | One set to `5.0V` for logic, one set to `6.0V` for motors |
| Samsung `18650` `2500 mAh` `20 A` cells | 2 | ordered | `20.90 EUR` total | Main battery pack |
| `42 x 19 mm` wheels | 2 working pairs | ordered | see order history | Both wheel pairs are driven in the current 4WD build |
| `1000 uF / 16 V` capacitor | 1 | ordered | `0.929 EUR` | Motor rail decoupling |
| Slide switch | 1 | ordered | `4.83 EUR` | Master power switch |
| `TCS34725` RGB color sensor `CJMCU-34725` | 2 ordered / 1 used | ordered | `9.40 EUR` total | Cam 2 floor color telemetry; purchase evidence in `Order3.png` |
| N20 6V DC gearmotors | 4 | existing or lab stock, to be confirmed | not counted yet | Motor voltage fixed at `6V`; two motors are wired in parallel per TB6612 channel |
| 3D-printed chassis/enclosure | 1 | CAD present | material-dependent | Baseline OpenSCAD and real Fusion CAD exist; final print validation still pending |

Approximate visible reference-build BOM spend from the available order screenshots is about `110.94 EUR` in item costs, or `113.48 EUR` if the `Order3.png` sensor-shipping cost is included. This excludes any lab-stock electronics and any still-unconfirmed motor purchase.

## 15. Open Design Issues

The following issues remain open and shall be closed in later revisions:

1. Validate the final `2S 18650` mount physically for service access and impact safety.
2. Confirm gearbox ratio from calculation plus bench tests.
3. Validate whether the ordered `2S 3A` BMS and TB6612 channels can tolerate four-motor surge current.
4. Calibrate or explain the measured `VL53L0X` offset.
5. Convert downward color telemetry into closed-loop boundary/retreat behavior.
6. Calibrate click-to-drive using camera geometry or document the timed prototype limitation.

## 16. Revision Guidance for Verstapost 2

The minimum expected changes for the next revision of this specification are:

- replace remaining assumptions with measured values;
- add the exact battery holder geometry and updated chassis drawing;
- add measured motor speed, current, and push-force data;
- keep measured network latency statistics current;
- calibrate or explain measured ToF accuracy statistics;
- confirm BMS suitability under startup and stall current conditions.

## 17. Summary

This V1 specification defines a realistic and buildable sumo robot architecture that is now substantially implemented in the repository. The design is centered on an M5 ATOM controller, dual M5 AtomS3R-CAM Wi-Fi camera nodes, `2S 18650` battery power, browser-based teleoperation, ToF telemetry, Cam 2 color telemetry, and a path toward calibrated click-to-drive and arena-aware behavior.

The strongest current assets are the existing firmware, camera streaming, ToF/color telemetry, movement measurements, executed analysis notebooks, real Fusion CAD, and PCB files. The most important next steps are ToF calibration, camera-aware brownout retesting, enclosure/endurance validation, and closed-loop arena behavior.

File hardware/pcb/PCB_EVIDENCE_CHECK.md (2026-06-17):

# PCB Evidence Check

This checklist records the current PCB evidence package for the `ATOM Sumo` interconnect board.

## Available Evidence

| Evidence item | File | Status |
| --- | --- | --- |
| Latest schematic screenshot | [Schematic_ATOM-Sumo_2026-06-13.png](Schematic_ATOM-Sumo_2026-06-13.png) | available |
| Latest schematic source export | [SCH_ATOM-Sumo_2026-06-13.json](SCH_ATOM-Sumo_2026-06-13.json) | available |
| Latest PCB layout screenshot | [PCB_PCB_ATOM_SUMO_2026-06-13.png](PCB_PCB_ATOM_SUMO_2026-06-13.png) | available |
| Latest PCB layout source export | [PCB_PCB_ATOM_SUMO_2026-06-13.json](PCB_PCB_ATOM_SUMO_2026-06-13.json) | available |
| Additional PCB screenshot | [PCB_extra_screenshot_2026-06-13_235021.png](PCB_extra_screenshot_2026-06-13_235021.png) | available |
| PCB 3D view | [3d.png](3d.png) | available |
| Latest Gerber archive | [Gerber_ATOM-Sumo_PCB_ATOM_SUMO_2026-06-17.zip](Gerber_ATOM-Sumo_PCB_ATOM_SUMO_2026-06-17.zip) | current manufacturing export; contains top/bottom copper, silkscreen, paste mask, solder mask, board outline, and PTH/NPTH drill files |
| Older Gerber archive | [Gerber_ATOM-Sumo_PCB_ATOM_SUMO_2026-04-08.zip](Gerber_ATOM-Sumo_PCB_ATOM_SUMO_2026-04-08.zip) | previous export, kept for traceability |
| Extra source archive | [Gerber_ATOM-Sumo_PCB_ATOM_SUMO_2026-04-08-2.zip](Gerber_ATOM-Sumo_PCB_ATOM_SUMO_2026-04-08-2.zip) | available; contains nested EasyEDA schematic/PCB JSON export |

## Electrical Intent Covered By The Board

The PCB package supports the project wiring concept:

- M5 ATOM main controller breakout;
- TB6612FNG motor-driver wiring;
- left motor pair and right motor pair wiring;
- logic/sensor connectors;
- shared ground and separated motor/logic rails according to the documented power scheme.

Related files:

- [BOM.csv](../../docs/specification/BOM.csv)
- [power_scheme.md](../../docs/specification/power_scheme.md)
- [Schematic_ATOM-Sumo_2026-06-13.png](Schematic_ATOM-Sumo_2026-06-13.png)

## Remaining Production Evidence

The current repository has schematic/layout screenshots, source JSON, 3D PCB evidence, and the latest `2026-06-17` Gerber archive with manufacturing layers and drill files. This is sufficient for the Verstapost `PCB evidence` requirement.

For stronger production-readiness evidence, add one or both of these optional files:

- `hardware/pcb/DRC_pass_YYYY-MM-DD.png`
- `hardware/pcb/Gerber_export_confirmation_YYYY-MM-DD.png`

Recommended capture steps:

1. Open the latest PCB project in EasyEDA.
2. Run Design Rule Check.
3. Capture the result window showing no blocking errors, or record the exact warnings.
4. Export Gerber/manufacturing files.
5. Capture the export confirmation or generated archive screen.

## Current Status

The PCB package is complete enough as design/source/current-Gerber evidence for Verstapost 1-3. A dedicated DRC pass screenshot is still useful for final production confidence, but V2 `PCB evidence` can be marked complete.

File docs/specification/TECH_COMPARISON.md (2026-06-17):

# Technical Comparison and Design Rationale

This document records the main technical tradeoffs behind the `ATOM Sumo` prototype.

It supports the Verstapost 1 specification and the final Verstapost 5 handover by explaining why the current architecture was selected and what alternatives were considered.

Related Estonian comparative analysis:

- [Vordlev_analyys.docx](../analysis/Vordlev_analyys.docx)
- [Vordlev_analyys_summary.md](../analysis/Vordlev_analyys_summary.md)

## 1. Main Controller Architecture

| Option | Advantages | Disadvantages | Decision |
| --- | --- | --- | --- |
| Android phone as robot brain | camera, display, battery, high-level compute already included | harder low-level motor wiring, less reproducible mechanical integration, needs phone-specific app path | not selected |
| ESP32 / M5 ATOM main controller | simple motor control, Wi-Fi AP, Arduino workflow, compact, reproducible | less compute for heavy vision | selected |
| Raspberry Pi / Linux SBC | strong OpenCV support, easy camera processing | higher power, slower boot, more fragile power setup, heavier | not selected for current prototype |

Decision:
- The robot uses an `M5 ATOM` / ESP32 as the onboard controller.
- Phone/laptop remains the browser client, not the robot brain.

Reason:
- The repository already contains working ESP32 firmware, browser control, motor control, ToF telemetry, and camera-node integration.
- This is easier to reproduce for a course prototype than a phone-as-brain build.

Evidence:
- [main firmware](../../firmware/main/main.ino)
- [main web UI](../../firmware/main/01_WebUi.ino)

## 2. Camera Architecture

| Option | Advantages | Disadvantages | Decision |
| --- | --- | --- | --- |
| Single onboard camera | fewer parts, simpler power | cannot easily serve both operator view and downward sensing | not enough |
| Two AtomS3R-CAM nodes | separate front and downward views, independent static IPs, browser-visible streams | more Wi-Fi/power load, two boards to flash | selected |
| USB camera to SBC | good software ecosystem | requires Linux SBC and stronger power budget | not selected |

Decision:
- Use two `M5 AtomS3R-CAM` nodes:
  - Cam 1: front/operator view at `192.168.4.20`;
  - Cam 2: downward view and color sensor telemetry at `192.168.4.21`.

Reason:
- The dual-node design lets the ESP32 main controller stay focused on motor/sensor control while cameras serve video over HTTP.

Evidence:
- [camera firmware](../../firmware/camera/sketch_jan17a/sketch_jan17a.ino)
- [main web UI](../../firmware/main/01_WebUi.ino)

## 3. Drive System

| Option | Advantages | Disadvantages | Decision |
| --- | --- | --- | --- |
| Two driven wheels + passive support wheels | simple, low cost, easy to test and measure | lower pushing force with small N20 motors | considered, not final |
| Four driven wheels with two motors per side wired in parallel | better traction and roughly doubles available motor torque with the same two-channel control model | higher current per TB6612 channel, must be validated | selected |
| Tracks / SMARS-style treads | good contact area, sumo-friendly | more friction, harder mechanical sourcing, more current | possible future revision |

Decision:
- Current build uses `4WD`: two left motors are wired in parallel to one TB6612 channel, and two right motors are wired in parallel to the other TB6612 channel.

Reason:
- With small `N20 / GA12-N20` class motors, the system benefits from summing motor torque across four wheels.
- The firmware can still use differential two-channel control because the motors are grouped by side.
- Movement measurements already exist for speed, drift, turning, and ToF stop behavior.
- The tradeoff is higher channel current, so brownout and driver-heating tests are required.

This matches the separate Estonian `Vordlev analyys` document: small N20/GA12-N20 class motors are close to the motor-limited region, so adding motors can increase usable pushing force. Competition robots with much stronger motors are usually traction-limited instead, so adding more motor power does not help unless grip or mass also increases.

Evidence:
- [movement_speed_test.csv](../../tests/results/movement_speed_test.csv)
- [movement_drift_test.csv](../../tests/results/movement_drift_test.csv)
- [movement_turn_test.csv](../../tests/results/movement_turn_test.csv)

## 4. Motor Driver and Power

| Option | Advantages | Disadvantages | Decision |
| --- | --- | --- | --- |
| TB6612FNG | common, compact, supports two DC motors, good Arduino support | current margin must be checked | selected |
| L298N | common and robust-looking | inefficient, voltage drop, bulky | not selected |
| Direct transistor/MOSFET per motor | flexible | more design risk and PCB effort | not selected |

Decision:
- Use `TB6612FNG` with a regulated `6.0V` motor rail. Each output channel drives two motors in parallel.

Reason:
- The motors are treated as `N20 6V`; raw `2S` battery voltage can reach `8.4V` and should not be applied directly.
- The parallel-pair wiring keeps the control architecture simple, but current draw must be measured.

Evidence:
- [power_scheme.md](power_scheme.md)
- [BOM.csv](BOM.csv)

## 5. Battery Architecture

| Option | Advantages | Disadvantages | Decision |
| --- | --- | --- | --- |
| USB powerbank | easy bench power, integrated protection | bulky, weak motor-current story, poor enclosure fit | legacy only |
| 1S Li-Ion | simpler charging | needs boost for motors, higher current for same power | not selected |
| 2S 18650 | good energy, motor rail can be buck-regulated, common cells | needs BMS and validation | selected |

Decision:
- Use `2S 18650` with:
  - `5.0V` logic buck;
  - `6.0V` motor buck;
  - common ground;
  - BMS and master switch.

Remaining risk:
- the `2S 3A` BMS must still be checked under motor startup and stall-like load.

Evidence:
- [power_scheme.md](power_scheme.md)
- [power_tree.drawio.png](../../hardware/diagrams/power_tree.drawio.png)

## 6. Obstacle Sensing

| Option | Advantages | Disadvantages | Decision |
| --- | --- | --- | --- |
| VL53L0X ToF | direct distance in mm, simple I2C, fast enough for close obstacle logic | reflective/angle limitations, needs threshold tuning | selected |
| Camera-only obstacle detection | flexible, can detect shapes | needs calibration and vision processing | not primary |
| Ultrasonic sensor | cheap, simple | large, slower, poor for small angled surfaces | not selected |

Decision:
- Use `VL53L0X` as the front safety and obstacle sensor.

Evidence:
- [main firmware](../../firmware/main/main.ino)
- [tof_stop_test.csv](../../tests/results/tof_stop_test.csv)

Remaining work:
- fill [tof_accuracy_test.csv](../../tests/results/tof_accuracy_test.csv).

## 7. Boundary / Color Sensing

| Option | Advantages | Disadvantages | Decision |
| --- | --- | --- | --- |
| Downward camera color detection | no extra sensor, flexible | needs image processing and stable lighting | secondary/future |
| TCS34725 color sensor | direct RGB/clear values, simpler thresholds, fast polling | sees only a local spot | selected for Cam 2 |
| Reflectance sensor array | good line/boundary detection | needs extra wiring and placement | possible future improvement |

Decision:
- Add a `TCS34725` color sensor to Cam 2 Grove I2C.

Reason:
- It gives fast local color telemetry without forcing full image processing on the main controller.

Evidence:
- [camera firmware](../../firmware/camera/sketch_jan17a/sketch_jan17a.ino)
- [main web UI](../../firmware/main/01_WebUi.ino)

Remaining work:
- measure repeatability on actual arena surfaces;
- implement closed-loop retreat or marked-area behavior.

## 8. Tap-Drive / Positioning

| Option | Advantages | Disadvantages | Decision |
| --- | --- | --- | --- |
| Timed tap-drive | quick to implement, demonstrates UI workflow | not geometrically accurate | current prototype |
| Calibrated camera raycast / homography | measurable target accuracy | requires calibration images/notebook | next step |
| ArUco arena positioning | global pose awareness, strong V5 story | requires marker setup and vision processing | future work |

Decision:
- Current implementation uses timed tap-drive from camera image position.
- It is acceptable as a prototype but not as final calibrated positioning.

Evidence:
- [main web UI](../../firmware/main/01_WebUi.ino)

Remaining work:
- add calibration notebook;
- measure click-to-drive target error;
- implement ArUco or document a simpler approved alternative.

## 9. Summary

The selected architecture favors fast, reproducible integration:

- ESP32/M5 main controller for control and web UI;
- two AtomS3R-CAM nodes for video;
- VL53L0X for front distance;
- TCS34725 for downward color telemetry;
- TB6612FNG and regulated `6.0V` motor rail;
- 4WD using two parallel motor pairs on the two TB6612 channels;
- `2S 18650` battery architecture.

This is a realistic choice for a course prototype because most subsystems are already implemented and measured. The remaining work is mainly calibration, repeatability measurements, production documentation, and final autonomous arena behavior.

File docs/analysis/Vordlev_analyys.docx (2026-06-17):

Võrdlev analüüs.

1. Võrdlusobjektide kirjeldus

Robot 1 — Advanced Sumo Robot (Arduino Nano ESP32)

Advanced Sumo Robot with Arduino Nano ESP32 | Arduino Project Hub (https://projecthub.arduino.cc/moath_momani/advanced-sumo-robot-with-arduino-nano-esp32-9a2682)

Kohandatud võistlussumorobot, mis põhineb 6 harjatavaba mootoril Maxynos THOR 2318 planetaarreduktoriga — 3 mootorit kummalgi küljel. Juhtimine toimub 2 ESC kaudu (45A, kahesuunaline, üks kummalgi küljel) — 2WD arhitektuur kolmikmootoriga külje kohta. Täisautonoomne süsteem 8 IR-vastase tuvastamise anduri, 4 servaanduri ning LiPo akuga 3S 11.1V 2200mAh. Korpus trükitud 3D-printeriga.

Robot 2 — Predator Mini Sumo Robot Kit (JSumo)

Predator Mini Sumo Robot Kit (Full Kit - Not Assembled) Price Jsumo | JSumo (https://www.jsumo.com/predator-mini-sumo-robot-kit-full-kit-not-assembled)

Kommertskomplekt mini-sumo kategooria võistlusteks (kuni 500 g, 10×10 cm). CNC-freesitud alumiiniumkorpus. Mootorid: Core DC 6V 400 RPM (2 tk). Juhtplaat Genesis V.2 Arduino Nano baasil. SLT20 silikoonkattega rattad. Autonoomne süsteem. Aku LiPo 3S 11.1V 450 mAh.

Robot 3 — Tallinn ATOM

Isetehtud robot kaugjuhtimisega nutitelefoni kaudu. 4 vedavat ratast, mootorid GA12-N20 (6V, 300 RPM). Kontroller M5 ATOM koos kaameratega (M5 ATOM Cam moodulid) + laserkaugusandur VL53L0X (ToF, I2C, kuni 2m). Toide: 2× Samsung Li-Ion 18650 (2S, 7.4V nominaal) koos DC/DC step-down muunduritega (üks mootoritele ~6V, teine kontrollerile). Mitteautonoomne — operaator juhib reaalajast nutitelefonist.

2. Struktureeritud võrdlus

Parameeter | Robot 1 (Arduino ESP32) | Robot 2 (Predator JSumo) | Tallinn ATOM
Ajami tüüp | 2WD (6 mootorit, 3 külje kohta) | 2WD (2 DC mootorit) | 4WD (4 DC mootorit)
Mootori tüüp | Maxynos THOR 2318, planetaarreduktor, harjatavaba | Core DC Gear Motor, 6V, 400 RPM | GA12-N20, 6V, 300 RPM
Toide | LiPo 3S 11.1V, 2200 mAh | LiPo 3S 11.1V, 450 mAh | Li-Ion 2S 7.4V (2× 18650) + DC/DC step-down
ESC juhtimine | 45A, kahesuunaline, PWM 80 Hz | Sisseehitatud draiver Genesis V.2 | Sisseehitatud draiver (H-bridge)
Kontroller | Arduino Nano ESP32 | Genesis V.2 (Arduino Nano) | M5 ATOM
Juhtimissüsteem | Autonoomne (8 IR + 4 servaandurit) | Autonoomne (3 IR + 2 servaandurit) | Kaugjuhtimine (nutitelefon, teleoperation)
Tuvastusandurid | 8× IR + TFmini LiDAR | 3× MR45 IR | 2× M5 ATOM Cam + VL53L0X ToF (laser, kuni 2m)
Korpus | 3D-trükk (PLA/PETG) | CNC alumiinium | Isetehtud
Rattad | Maxynos High Traction 2" (51 mm) | SLT20 silikoon (33 mm) | Pololu 42×19 mm (r = 21 mm)
Piirav tegur | Traction-limited | Traction-limited | Motor-limited
Rakendusala | Võistlused (full sumo) | Võistlused (mini sumo) | Õppimisprotüüp / teleoperation

3. Pöördemomendi ja tõukejõu numbriline analüüs

Tõukejõu arvutuse valem:

F = T_total / r

kus:

- F — tõukejõud [N]
- T_total — ajami kogupöördemoment [N·m]
- r — ratta raadius [m] (võetud r = 0.02 m robotitele 1 ja 2; r = 0.021 m robotile 3, ratas 42×19 mm)

Robot 1 — Maxynos THOR 2318 (harjatavaba, planetaarreduktor)

Mootori THOR 2318 omadused planetaarreduktoriga:

- Harjatavaba mootor planetaarreduktoriga, toide 11.1V (3S LiPo)
- Hinnanguline väljundmoment reduktoril: ~0.5–1.2 N·m mootori kohta (tüüpiline vahemik selle klassi jaoks)
- 6 mootorit (3 külje kohta, 2 külge) → T_total ≈ 3.0–7.2 N·m

Jõu arvutus:

F = T_total / r = 6.0 / 0.02 = 300 N (keskmine väärtus)

Süsteem on haardepiiranguga (traction-limited): hõõrdeteguri μ ≈ 0.8 ja massi ~1 kg korral:

F_traction_max = μ × m × g = 0.8 × 1.0 × 9.81 ≈ 7.85 N

Mootorid suudavad genereerida jõudu, mis ületab haardepiirangu ~38 korda → süsteem on sügavalt traction-limited režiimis. Võimsuse suurendamine ei oma mõtet ilma roboti massi suurendamise või rehvide parandamiseta.

Robot 2 — Core DC 6V, 400 RPM (JSumo Predator)

JSumo Core mootori omadused (6V, 400 RPM):

- Tüüpiline seiskumismoment (stall torque): ~0.08–0.12 N·m mootori kohta
- Kaks mootorit → T_total ≈ 0.16–0.24 N·m

Jõu arvutus:

F = T_total / r = 0.20 / 0.02 = 10 N (keskmine)

Massi ~0.5 kg (mini sumo limiit) ja μ ≈ 0.9 (SLT20 silikoonrattad) korral:

F_traction_max = 0.9 × 0.5 × 9.81 ≈ 4.41 N

Mootorid genereerivad ~10 N, haardepiirang ~4.4 N → süsteem on samuti traction-limited, kuid väiksema varuga võrreldes robotiga 1.

Tallinn ATOM — GA12-N20, 6V, 300 RPM (4WD)

Andmed on määratud:

- Ühe mootori moment: T₁ = 0.018 N·m
- Neli mootorit → T_total = 0.072 N·m

Jõu arvutus:

F = T_total / r = 0.072 / 0.021 = 3.43 N

Õppimisprotüübi tüüpilise massi ~0.5–0.8 kg ja μ ≈ 0.6 korral:

F_traction_max = 0.6 × 0.65 × 9.81 ≈ 3.83 N

Genereeritav jõud (3.43 N) on lähedal haardepiirangule (3.83 N) → süsteem töötab motor-limited / traction-limited piiril.

Numbrilise analüüsi koondtabel

Parameeter | Robot 1 (THOR 2318) | Robot 2 (Core 400 RPM) | Tallinn ATOM
Mootoreid | 6 (3 külje kohta) | 2 | 4
T mootori kohta [N·m] | ~1.0 | ~0.10 | 0.018
T_total [N·m] | ~6.0 | ~0.20 | 0.072
F arvutuslik [N] | ~300 | ~10 | 3.43
F_traction_max [N] | ~7.85 | ~4.41 | ~3.83
Piirav tegur | Traction-limited | Traction-limited | Motor-limited
Momendi varu | ~38× | ~2× | < 1×

4. Traction-limited vs Motor-limited: kontseptuaalne erinevus

Traction-limited süsteem — mootorid genereerivad momenti, mis ületab rataste maksimaalse haardejõu pinnaga. Formaalselt:

F_motor > F_traction_max

Selles režiimis on jõudlust piiratud mitte mootori võimsus, vaid rehvi–pinna kontakti füüsika. Võimsamate mootori lisamine ei anna tõukejõu kasvu — rattad hakkavad niikuinii libisema. Parandus saavutatakse roboti massi suurendamise, rehvide materjali parandamise (silikoon > kautšuk) või kontaktpinna suurendamise kaudu.

Motor-limited süsteem — mootorid ei suuda arendada piisavat momenti haarde täieliku potentsiaali kasutamiseks:

F_motor < F_traction_max

Selles režiimis suurendab mootori lisamine või reduktori ülekandearvu suurendamine otseselt tõukejõudu. Just see on realiseeritud Tallinn ATOM prototüübis üleminekuga 2WD-lt 4WD-le.

5. Miks kasutavad võistlussumorobotid 2WD-d

Võistlusrobotid (Robot 1 ja 2) kasutavad 2WD-d järgmistel insenerlikel põhjustel:

1. Mass: võistluskategooriates on mass rangelt piiratud (mini sumo: 500 g, sumo: 3 kg). Kaks võimsat mootorit + ESC + planetaarreduktor paigutavad massi efektiivsemalt kui neli väikese võimsusega mootorit eraldi draiveritega.

2. Juhitavus: diferentsiaalajamiga 2WD tagab täpse pööramisjuhtimise (üks ratas edasi, teine tagasi = pöörlemine paigal). 4WD nõuab keerukamat juhtimissüsteemi või mehaanilist diferentsiaali.

3. Töörežiim: kõrgmomendiliste mootorite kasutamisel (Robot 1: THOR 2318, 6 mootorit) on süsteem traction-limited varuga ~38×. Mootori arvu suurendamine üle praeguse 6 ei anna tõukejõu kasvu — kõik rattad kasutavad juba kogu haardereservi. Ainus tee tõukejõu suurendamiseks on roboti massi suurendamine või rehvide materjali parandamine.

4. Töökindlus: vähem mootoreid = vähem rikkekohti, vähem elektriskeemi keerukust, vähem juhtmestiku kaalu.

6. Miks on väikese võimsusega mootoritega süsteemides otstarbekas 4WD

GA12-N20 mootoritega (T₁ = 0.018 N·m) on süsteem motor-limited. See tähendab, et:

T_2WD = 2 × 0.018 = 0.036 N·m → F = 1.71 N

T_4WD = 4 × 0.018 = 0.072 N·m → F = 3.43 N

Üleminek 2WD-lt 4WD-le kahekordistab tõukejõu ilma mootoreid vahetamata. See on otsene ja põhjendatud inseneriotsus piiratud eelarve ja komponentide kättesaadavuse tingimustes.

Lisaeelised 4WD puhul väikese võimsusega mootoritega:

- Koormuse jaotus 4 kontaktpunktile → spetsiifilise rõhu vähendamine, haarde parandamine ebatasastel pindadel
- Üksikute rataste libisemise riski vähendamine
- Platvormi stabiilsuse suurendamine kaameratega teleoperatsiooni ajal

7. Insenerlik järeldus 4WD valiku kohta Tallinn ATOM jaoks

Miks valiti 4WD

4WD valik Tallinn ATOM jaoks on tehniliselt põhjendatud otsus järgmiste piirangute tingimustes:

1. Komponentide kättesaadavus: GA12-N20 on üks levinumaid ja kättesaadavamaid mikromootoreid. T₁ = 0.018 N·m korral annab kaks mootorit F = 1.71 N — ebapiisav aktiivseks vastupanoks.
2. Motor-limited režiim: 2WD puhul ei suuda mootorid kasutada haarde täielikku reservi. 4WD viib süsteemi traction-limited lähedale (F_motor ≈ F_traction), mis on optimaalne insenerlik seisund.
3. Momendi puudujäägi kompenseerimine: 4WD kompenseerib ühe mootori madalat momenti paralleelse summeerimise kaudu:

ΔF = (T_4WD - T_2WD) / r = (0.072 - 0.036) / 0.021 = 1.71 N juurdekasv

See on 100% suurenemine ilma mootori tüüpi muutmata.

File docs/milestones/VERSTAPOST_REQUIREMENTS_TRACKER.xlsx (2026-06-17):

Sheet: Requirements
Verstapost | No. | Requirement | Done (+) | Status | Completion | Priority | Evidence 1 | Evidence 2 | Evidence 3 | Evidence 4 | Evidence 5 | Notes / remaining work
Verstapost 1 | 1 | Select and describe project concept | + | closed | Done | OK | V1_specification.md | Versta1.png |  |  |  | none
Verstapost 1 | 2 | Define architecture and main subsystems | + | closed | Done | OK | V1_specification.md | system_block.drawio.png |  |  |  | none
Verstapost 1 | 3 | Explain deviation from original Android-phone brief | + | closed | Done | OK | V1_specification.md | TECH_COMPARISON.md |  |  |  | none
Verstapost 1 | 4 | Functional requirements and priorities | + | closed | Done | OK | V1_specification.md |  |  |  |  | none
Verstapost 1 | 5 | Performance targets | + | closed | Done | OK | V1_specification.md |  |  |  |  | later compare with final tests
Verstapost 1 | 6 | BOM with procurement status | + | closed | Done | OK | BOM.csv | Order1.png | Order2.png |  |  | final release BOM still needs exact sources for all actual build parts
Verstapost 1 | 7 | Power architecture | + | closed | Done | OK | power_scheme.md | power_tree.drawio.png | power_brownout_test.csv |  |  | direct current measurement and camera-aware brownout retest still needed
Verstapost 1 | 8 | Testing plan | + | closed | Done | OK | test_plan.md |  |  |  |  | keep updated as measurements are added
Verstapost 1 | 9 | Design evidence | + | closed | Done | OK | hardware/cad/ver1 | hardware/pcb/README.md | main | cam |  | none for V1
Verstapost 1 | 10 | Comparative/tradeoff analysis | + | closed | Done | OK | TECH_COMPARISON.md | Vordlev_analyys_summary.md | Vordlev_analyys.docx |  |  | update if the architecture changes
Verstapost 2 | 1 | Demonstrate control chain from browser to motors | + | closed | Done | OK | main firmware | web UI | motion logic |  |  | none
Verstapost 2 | 2 | Robot Wi-Fi AP and web server | + | closed | Done | OK | main firmware | web handlers |  |  |  | none
Verstapost 2 | 3 | Manual movement commands | + | closed | Done | OK | main UI | movement_speed_test.csv |  |  |  | motor trim can be improved
Verstapost 2 | 4 | Speed/drift/turn measurements | + | closed | Done | OK | movement_speed_test.csv | movement_drift_test.csv | movement_turn_test.csv | tof_stop_test.csv |  | none
Verstapost 2 | 5 | HTTP latency measurement | + | closed | Done | OK | http_latency_analysis.ipynb | latency_test_result.md | test_results_analysis.ipynb |  |  | update after new latency runs
Verstapost 2 | 6 | Camera stream evidence | + | closed | Done | OK | camera firmware | demo video |  |  |  | add newer demo video if available
Verstapost 2 | 7 | ToF integration | + | closed | Done | OK | main firmware | tof_stop_test.csv | tof_accuracy_test.csv | tof_accuracy_collect.py | ToF calibration note | Offset measured and documented; correction model valid for 50-300 mm short/medium obstacle logic; retest after final mounting.
Verstapost 2 | 8 | PCB evidence | + | closed | Complete | Done | hardware/pcb/README.md | PCB evidence check |  |  | Latest Gerber/drill archive 2026-06-17 | Closed: schematic/layout PNG+JSON, 3D PCB screenshot, and latest 2026-06-17 Gerber/drill manufacturing archive are present. DRC screenshot remains optional production evidence.
Verstapost 2 | 9 | Power robustness | + | closed | Complete | Done | power_brownout_test.csv | power_brownout_test.py | Power brownout analysis | Power brownout retest 2026-06-17 | Power brownout retest summary | Closed for documented operating range PWM 80-180: final retest has 30/30 rows with reset=no and Wi-Fi disconnect=no; browser camera observed during test. PWM 255 is documented as outside stable operating range.
Verstapost 3 | 1 | Integrate motors, cameras, sensors, and UI | + | closed | Done | OK | main UI | main | cam |  |  | none for integration claim
Verstapost 3 | 2 | Show both camera streams in operator UI | + | closed | Done | OK | main UI |  |  |  |  | add current demo video if possible
Verstapost 3 | 3 | Front ToF telemetry in UI | + | closed | Done | OK | main UI | web handlers | tof_accuracy_test.csv |  |  | calibrate or explain measured offset
Verstapost 3 | 4 | Downward color telemetry | + | closed | Done | OK | camera firmware | main UI |  |  |  | color repeatability rows
Verstapost 3 | 5 | Click/tap-to-drive | + | closed | Complete | Done | main UI | Tap-drive algorithm | Camera calibration and tap-drive plan | Tap-drive accuracy template | Tap-drive accuracy summary | Closed: timed tap-drive algorithm measured in 5 physical trials; 5/5 pass, median error 20 mm, max error 141.4 mm. Red servo disabled; future improvement is pixel logging/homography calibration.
Verstapost 3 | 6 | Camera calibration | + | closed | Complete | Done | Camera calibration and tap-drive plan | Camera calibration notebook | Executed camera calibration notebook | Homography calibration summary | Camera homography JSON/residuals | Closed: UI CALIB mode used to collect 6 real Cam1 homography points; generated pixel-to-arena JSON with median residual 45.0 mm and max 68.3 mm. Chessboard intrinsics remain optional future precision improvement.
Verstapost 3 | 7 | Boundary/color behavior | + | closed | Complete | Done | Cam2 color firmware | Color repeatability CSV | Color repeatability summary | TCS34725 purchase evidence Order3 | Firmware UI screenshots | Closed: Cam2 TCS34725 telemetry measured on red/light/dark surfaces; classifier threshold fixed and flashed; UI confirmed COLOR DARK; purchase and UI screenshot evidence added. Closed-loop color retreat is not claimed.
Verstapost 3 | 8 | Simple autonomous behavior |  | partial | Partial | Fix / measure | Auto behavior code | Auto behavior logger | Auto behavior observation | Operator observation CSV | Auto logger UI screenshot | Partial: auto logger implemented, UI screenshots and video evidence indexed; operator observed turn/avoid at about 200 mm; battery depleted before full 5-trial logger CSV. Need charged robot run to close reliability claim.
Verstapost 4 | 1 | Enclosure/body CAD | + | closed | Done | OK | hardware/cad/ver3 | hardware/cad/real |  |  |  | none for CAD evidence
Verstapost 4 | 2 | Real mechanical CAD package | + | closed | Done | OK | hardware/cad/real/README.md |  |  |  |  | export final printable files if required
Verstapost 4 | 3 | Functional prototype software | + | closed | Done | OK | main | cam |  |  |  | none
Verstapost 4 | 4 | Color/marked-area sensing |  | partial | Partial | Fix / measure |  |  |  |  |  | repeatability and closed-loop behavior
Verstapost 4 | 5 | Enclosure impact/heat validation |  | open | Open | Missing |  |  |  |  |  | add measured test tables/photos
Verstapost 4 | 6 | Battery service/access validation |  | open | Open | Missing |  |  |  |  |  | add service time measurement
Verstapost 4 | 7 | Repeated match endurance |  | open | Open | Missing |  |  |  |  |  | add `90 s` repeated run log
Verstapost 4 | 8 | Assembly photos |  | partial | Partial | Fix / measure | ASSEMBLY_GUIDE.md | docs/assets/photos/README.md | docs/assets/photos/Image (1).jpg | docs/assets/photos/Mutimedia.jpg | docs/assets/photos/PXL_20260613_160049625.jpg | Partial: fabrication, electronics integration, printed enclosure, and assembled robot photos are indexed. Still add final multi-angle front/back/left/right/top photos for a stronger final package.
Verstapost 5 | 1 | Repository structure and index | + | closed | Done | OK | README.md | docs README | requirements tracker Excel |  |  | none
Verstapost 5 | 2 | Full milestone traceability | + | closed | Done | OK | requirements tracker Excel | docs index |  |  |  | keep links updated
Verstapost 5 | 3 | Firmware buildability | + | closed | Done | OK | FLASHING_GUIDE.md | main | camera firmware |  |  | re-validate on all boards before final handover
Verstapost 5 | 4 | CAD/PCB package | + | closed | Done | OK | cad | hardware/cad/real | hardware/pcb/README.md | PRINT_SETTINGS.md |  | final material validation and printable export cleanup
Verstapost 5 | 5 | Final limitations documented | + | closed | Done | OK | requirements tracker Excel | VERSTAPOSTID_PLAN.md |  |  |  | none
Verstapost 5 | 6 | Assembly guide |  | partial | Partial | Fix / measure | ASSEMBLY_GUIDE.md | docs/assets/photos/README.md | docs/assets/photos/Image (1).jpg | docs/assets/photos/Mutimedia.jpg | docs/assets/photos/PXL_20260613_160049625.jpg | Partial: assembly checklist and photo evidence are present. Still add final multi-angle photos plus battery service and endurance measurements.
Verstapost 5 | 7 | Flashing/setup guide | + | closed | Done | OK | FLASHING_GUIDE.md |  |  |  |  | re-check COM ports during final flashing
Verstapost 5 | 8 | Print settings |  | partial | Partial | Fix / measure | PRINT_SETTINGS.md | docs/assets/photos/Image.jpg | docs/assets/photos/Image (2).jpg | docs/assets/photos/PXL_20260613_160049625.jpg | docs/assets/photos/README.md | Partial: printed-part photo evidence is present. Still validate final material-specific heat, impact, battery-service, and endurance results.
Verstapost 5 | 9 | Final integrated measurement analysis | + | closed | Done | OK | test_results_analysis.ipynb | http_latency_analysis.ipynb |  |  |  | update notebook after new tests
Verstapost 5 | 10 | ArUco/global localization |  | open | Open | Missing |  |  |  |  |  | implement or document as future work

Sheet: Summary
Milestone | Total requirements | Closed | Partial | Open | Submission status | Notes
Verstapost 1 | 10 | 10 | 0 | 0 | Ready | Specification package is complete; keep final BOM/details updated.
Verstapost 2 | 9 | 9 | 0 | 0 | Ready | Key technology chain is proven; ToF accuracy, PCB DRC, and power/camera retest are weak spots.
Verstapost 3 | 8 | 7 | 1 | 0 | Ready with gap | Integrated technical prototype can be submitted; calibration and closed-loop behavior remain gaps.
Verstapost 4 | 8 | 3 | 2 | 3 | Not ready | CAD/software evidence exists, but enclosure validation/photos/endurance are missing.
Verstapost 5 | 10 | 7 | 2 | 1 | Ready with gaps | Repository and documentation package exists, but production validation is not complete.
Main submission file | VERSTAPOST_REQUIREMENTS_TRACKER.xlsx
Generated on | 2026-06-17

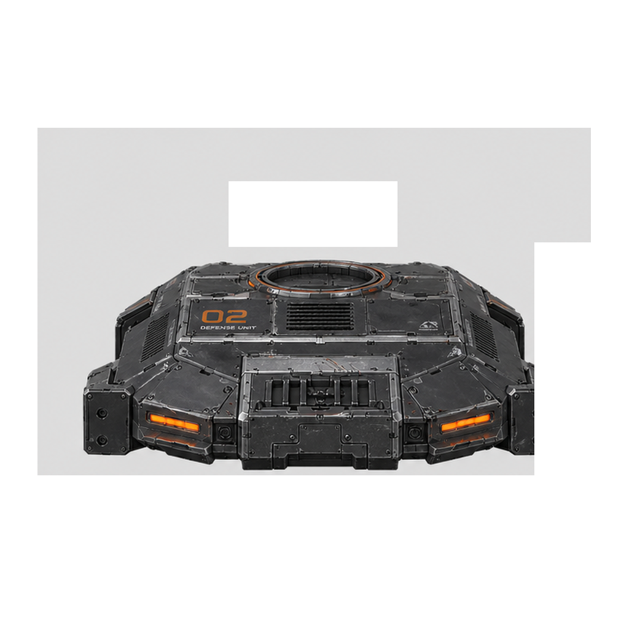
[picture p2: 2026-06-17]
hardware/cad/ver3/korpus_whiteout_views/korpus_whiteout_front.png

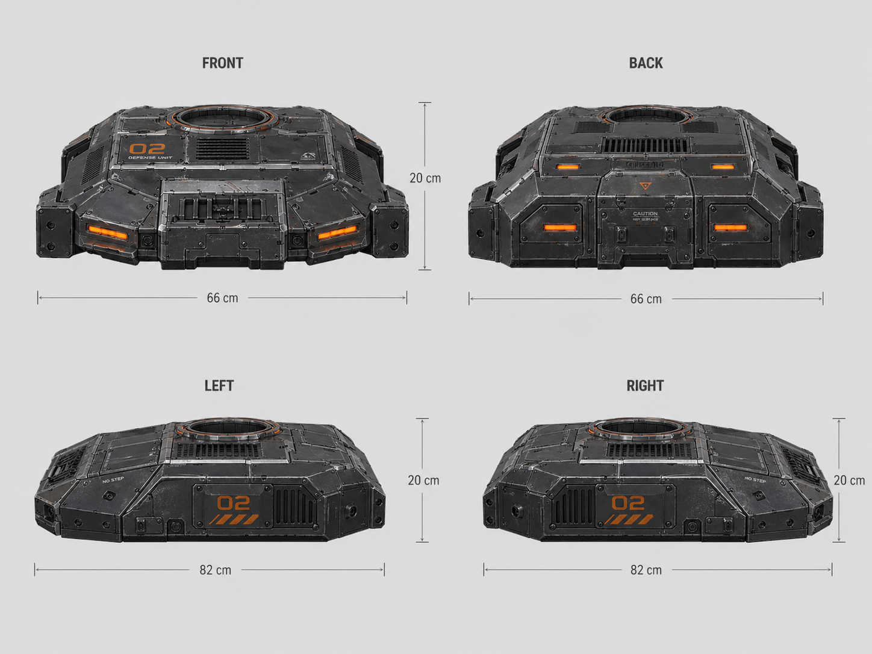
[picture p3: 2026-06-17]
hardware/cad/ver3/a12df667-bc1c-4a40-bf58-3ef6664fbbb0.png

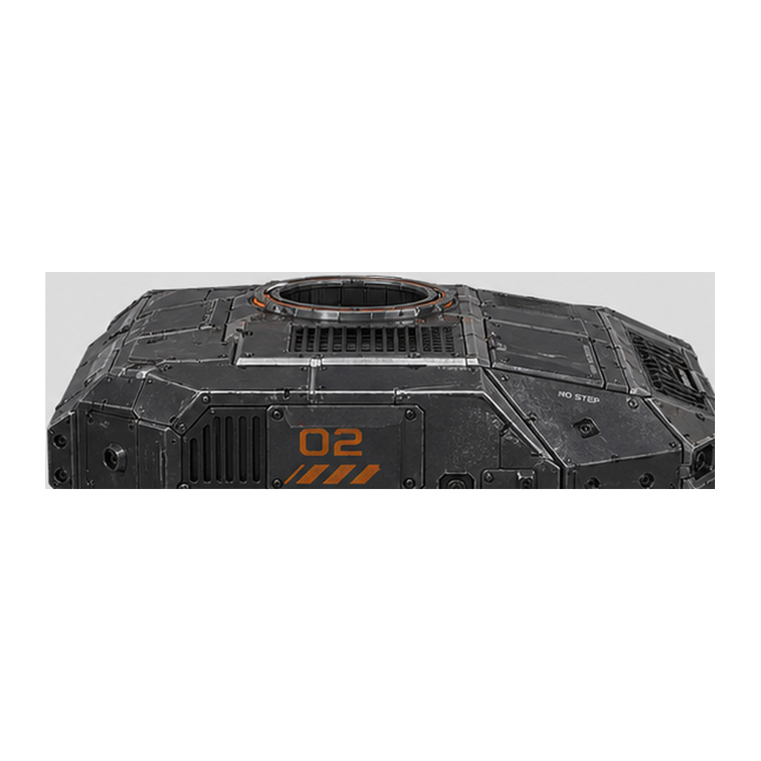
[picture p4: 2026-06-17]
hardware/cad/ver3/korpus_object_views/korpus_object_right.png

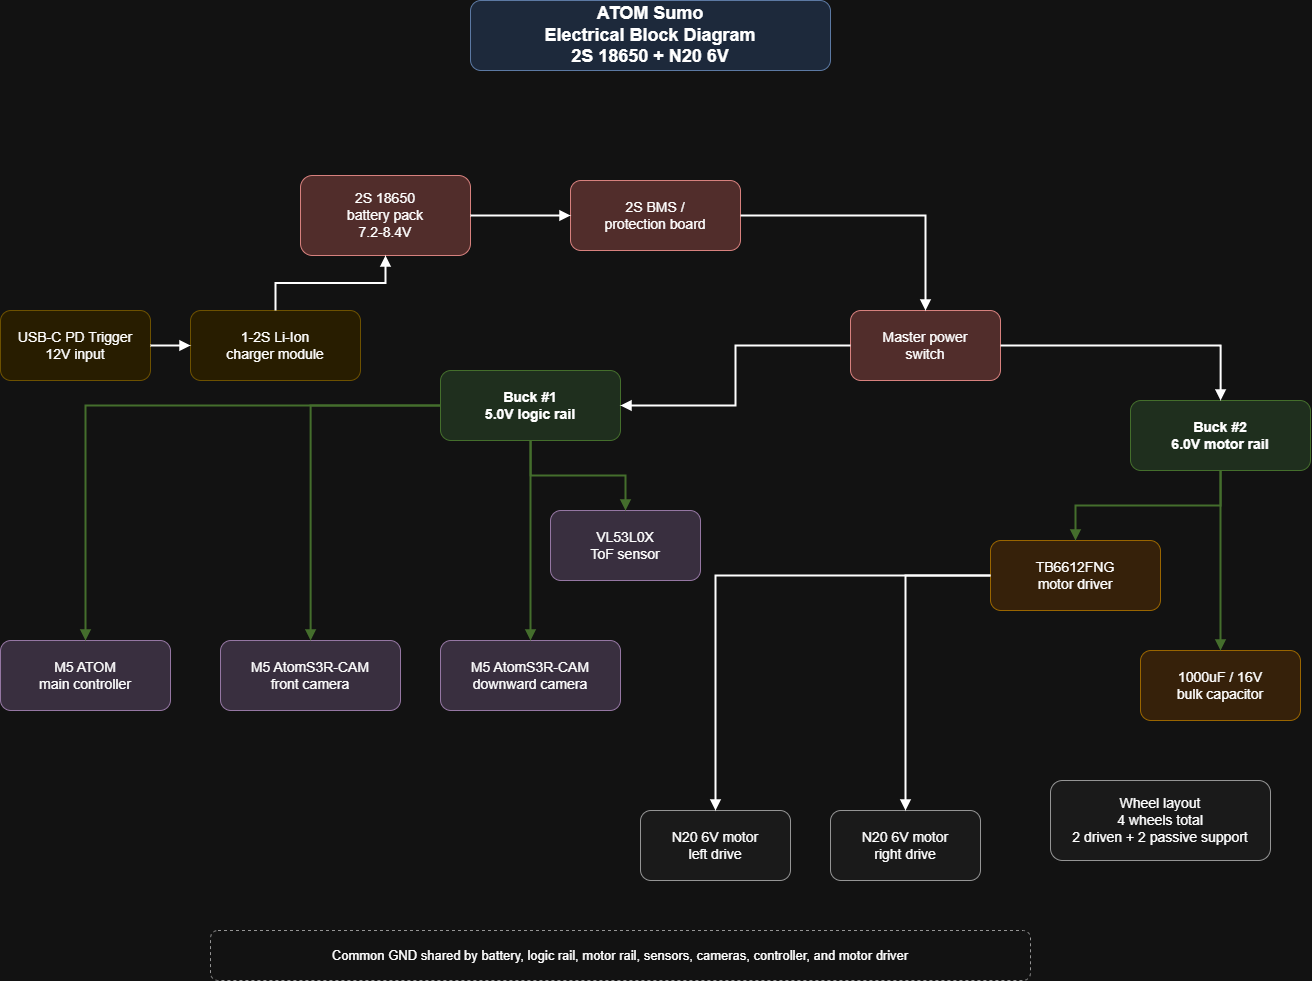
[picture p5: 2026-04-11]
hardware/diagrams/power_tree.drawio.png

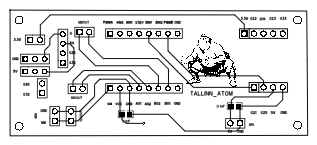
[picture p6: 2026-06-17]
hardware/pcb/PCB_PCB_ATOM_SUMO_2026-06-13.png

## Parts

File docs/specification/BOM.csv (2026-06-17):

line_id | part_name | manufacturer | part_number_or_model | category | function | qty_required | qty_ordered | unit_price_eur | total_price_eur | supplier | status | used_in_reference_build | order_ref | notes
BOM-001 | M5 ATOM main controller | M5Stack | ATOM | control_electronics | main_controller | 1 | 1 |  |  | assumed_available | assumed_available | yes | repo | Main controller used by main/main.ino
BOM-002 | M5 AtomS3R-CAM | M5Stack | AtomS3R-CAM | camera | front_and_downward_video | 2 | 2 |  |  | assumed_available | assumed_available | yes | repo | Two camera nodes used by cam/sketch_jan17a/sketch_jan17a.ino
BOM-003 | VL53L0X ToF module |  | GY-VL53L0X | sensor | front_distance_sensing | 1 | 1 | 9.50 | 9.50 | local_order_screenshot | ordered | yes | Order1.png | Front obstacle sensing over I2C
BOM-004 | TB6612FNG dual motor driver | SparkFun | ROB-14450 | motor_control | dual_dc_motor_driver | 1 | 1 | 13.36 | 13.36 | Mouser | ordered | yes | Order2.png | Main dual motor driver; one channel drives the left motor pair and one channel drives the right motor pair; current must be validated
BOM-005 | USB-C PD trigger module |  | 12V_0.5A | power | charging_input_source | 1 | 1 | 4.28 | 4.28 | local_order_screenshot | ordered | yes | Order1.png | Used as charging or bench setup input
BOM-006 | 1-2S Li-Ion charger module |  |  | power | battery_charging | 1 | 1 | 4.28 | 4.28 | local_order_screenshot | ordered | yes | Order1.png | Charging path for 2S 18650 pack
BOM-007 | 2x18650 battery holder |  | PCB_THT | power | battery_mount | 1 | 1 | 2.38 | 2.38 | local_order_screenshot | ordered | yes | Order1.png | Requires CAD integration
BOM-008 | 2S 3A BMS protection board |  |  | power | battery_protection | 1 | 1 | 2.85 | 2.85 | local_order_screenshot | ordered | yes | Order1.png | Must be surge tested with motors
BOM-009 | DC-DC step-down module 5A |  | 4.38V_to_36V | power | logic_and_motor_regulation | 2 | 2 | 11.40 | 22.80 | local_order_screenshot | ordered | yes | Order1.png | One set to 5.0V for logic and one set to 6.0V for motor rail
BOM-010 | 18650 Li-Ion cell | Samsung | 2500mAh_20A | power | main_battery_cell | 2 | 2 | 10.45 | 20.90 | local_order_screenshot | ordered | yes | Order1.png | 2S pack uses two cells in series
BOM-011 | Wheel set 42x19 mm driven pair |  | Pololu_2pk | drive_train | driven_wheel_pair | 1 | 1 | 5.93 | 5.93 | local_order_screenshot | ordered | yes | Order1.png | First driven wheel pair
BOM-012 | Wheel set 42x19 mm driven pair |  | Pololu_2pk | drive_train | second_driven_wheel_pair | 1 | 1 | 9.50 | 9.50 | local_order_screenshot | ordered | yes | Order1.png | Second driven wheel pair for 4WD; motors are wired as two left/right parallel pairs
BOM-013 | 1000uF 16V radial capacitor | TDK | B41858C4108M000 | power | motor_supply_bulk_capacitor | 1 | 1 | 0.929 | 0.929 | Mouser | ordered | yes | Order2.png | Motor rail bulk decoupling capacitor
BOM-014 | Slide switch | C_and_K | L201011MS02Q | power | master_power_switch | 1 | 1 | 4.83 | 4.83 | Mouser | ordered | yes | Order2.png | Master power switch
BOM-015 | RGB color sensor |  | TCS34725_CJMCU-34725 | sensor | cam2_floor_color_telemetry | 1 | 2 | 4.70 | 9.40 | Digipurk | ordered | yes | Order3.png | Two ordered; one used on Cam2 Grove I2C for TCS34725 color telemetry
BOM-016 | N20 6V DC gearmotor |  | N20_6V | drive_train | four_wheel_drive_motors | 4 | 4 |  |  | existing_or_lab_stock | to_be_confirmed | yes |  | Four motors total; two left motors share TB6612 channel A and two right motors share channel B; motor rail fixed at 6.0V
BOM-017 | Custom PCB |  |  | electronics_integration | main_interconnect_board | 1 | 0 |  |  | in_house_design | design_ready_not_ordered | yes | PCB_repo | Gerber and EasyEDA source already exist
BOM-018 | 3D printed chassis |  |  | mechanical | chassis_body | 1 | 0 |  |  | in_house | cad_complete_print_pending | yes | cad_repo | Generated from cad/ver1/chassis_n20.scad

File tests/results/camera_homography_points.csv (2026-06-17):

point_id | pixel_x | pixel_y | arena_x_mm | arena_y_mm | notes
P1 | 325 | 153 | 150 | 500
P2 | 100 | 131 | -220 | 760
P3 | 196 | 151 | 0 | 550
P4 | 34 | 164 | -200 | 250
P5 | 322 | 181 | 60 | 200
P6 | 143 | 127 | -150 | 1000

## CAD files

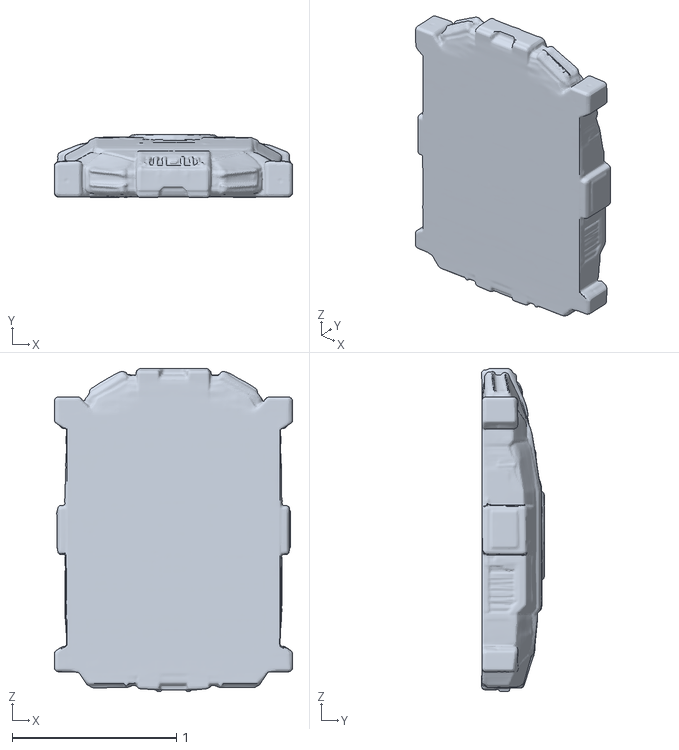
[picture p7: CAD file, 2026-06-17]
hardware/cad/ver3/korpus_purewhite_hq_4view_00001.stl
1.45 x 0.384 x 1.97

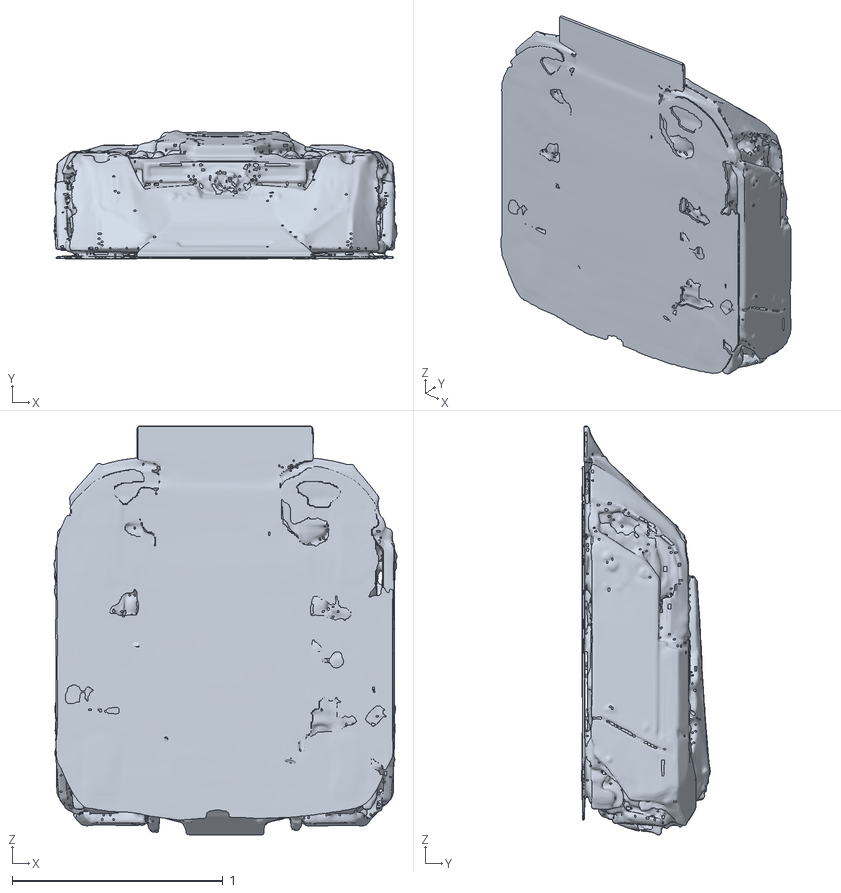
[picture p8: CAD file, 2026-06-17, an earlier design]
hardware/cad/ver2/parts/clean_main.obj
1.63 x 0.611 x 1.94

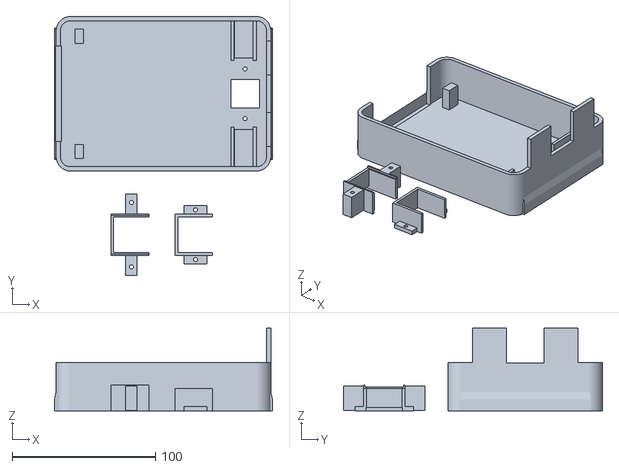
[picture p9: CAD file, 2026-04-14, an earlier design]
hardware/cad/ver1/chassis_n20_printable. small.stl
152.4 x 181.0 x 58.0

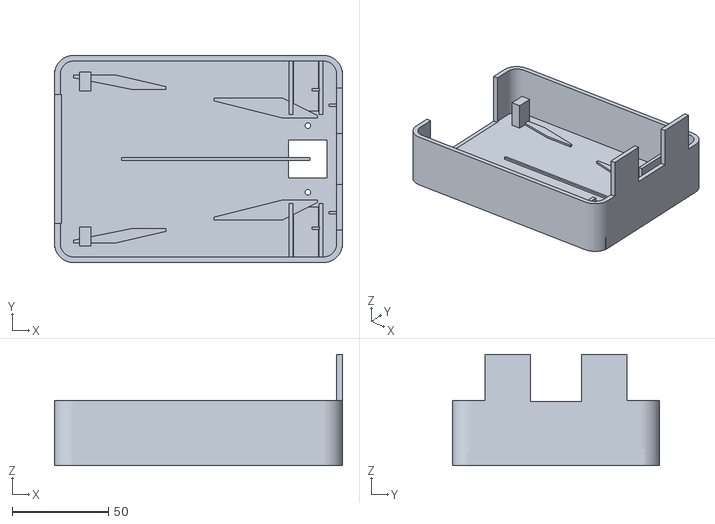
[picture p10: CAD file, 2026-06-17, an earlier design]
hardware/cad/ver1/output/chassis_n20_printable_core.stl
150.0 x 108.0 x 58.0

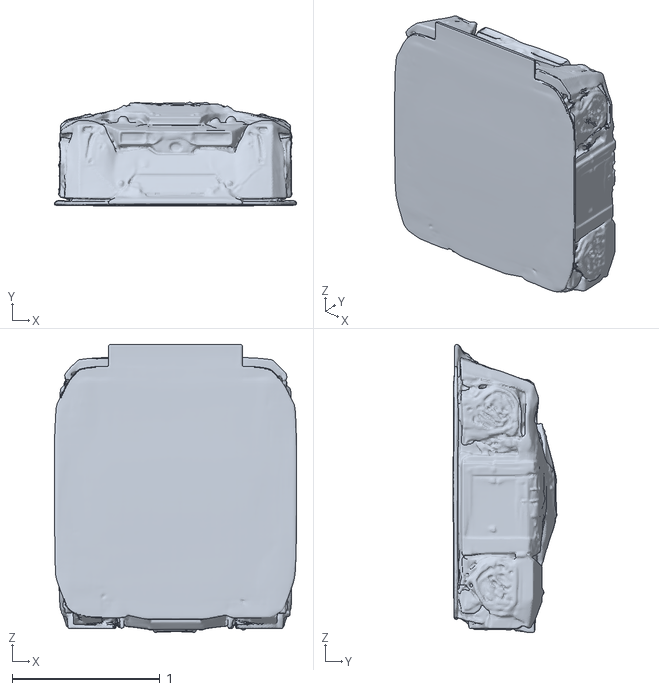
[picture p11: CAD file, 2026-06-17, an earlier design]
hardware/cad/ver2/comfy_multiview_latest_00007.obj
1.64 x 0.701 x 1.95

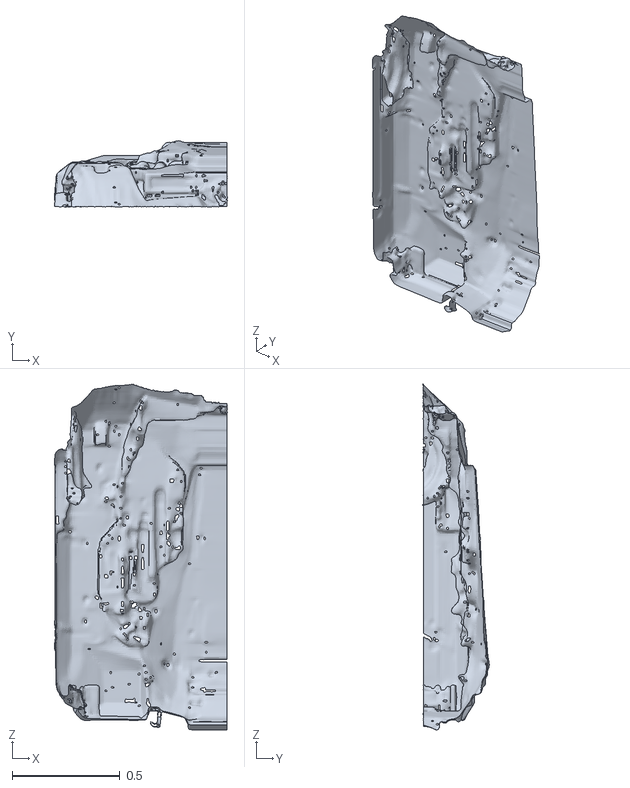
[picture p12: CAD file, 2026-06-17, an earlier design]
hardware/cad/ver2/parts/rear_left_quadrant.stl
0.805 x 0.309 x 1.61

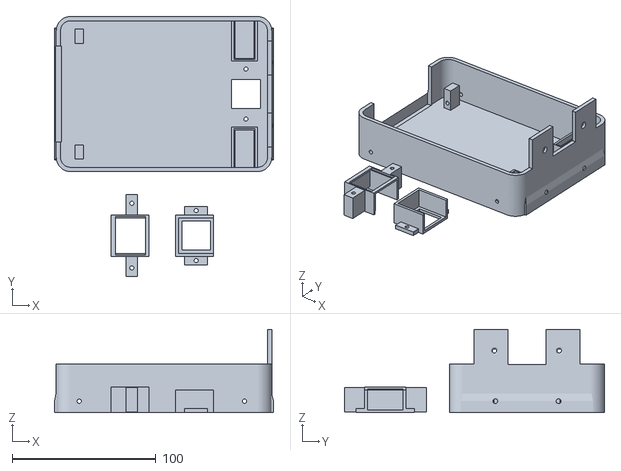
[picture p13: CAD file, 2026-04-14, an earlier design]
hardware/cad/ver1/chassis_n20_printable.stl
152.4 x 181.0 x 58.0

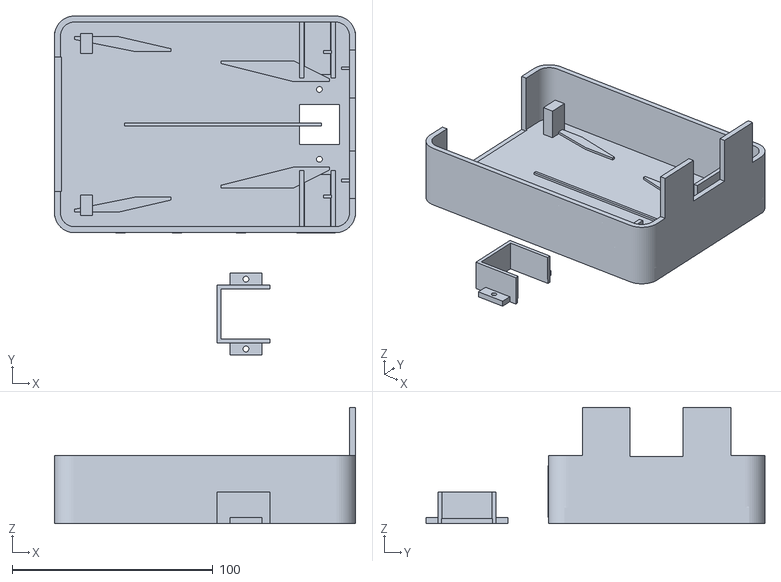
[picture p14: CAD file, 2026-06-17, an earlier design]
hardware/cad/ver1/output/chassis_n20_printable.stl
150.0 x 168.9 x 58.0

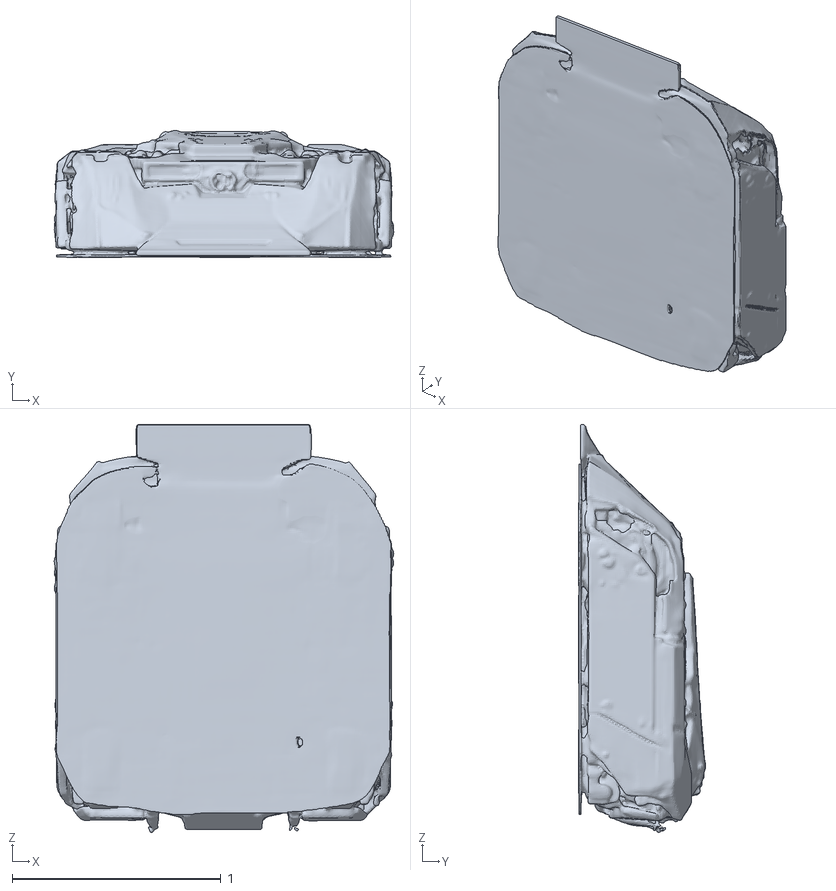
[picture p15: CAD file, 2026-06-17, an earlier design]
hardware/cad/ver2/comfy_multiview_4view_00001.obj
1.63 x 0.611 x 1.96

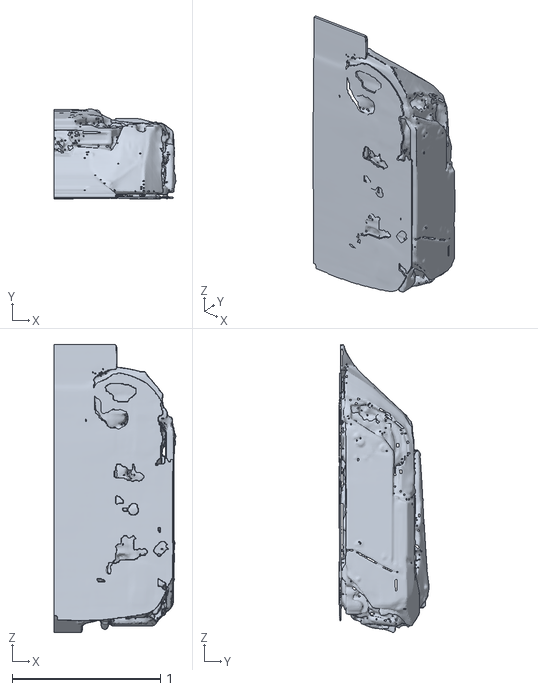
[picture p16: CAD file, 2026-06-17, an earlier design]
hardware/cad/ver2/parts/front_half.stl
0.82 x 0.608 x 1.94

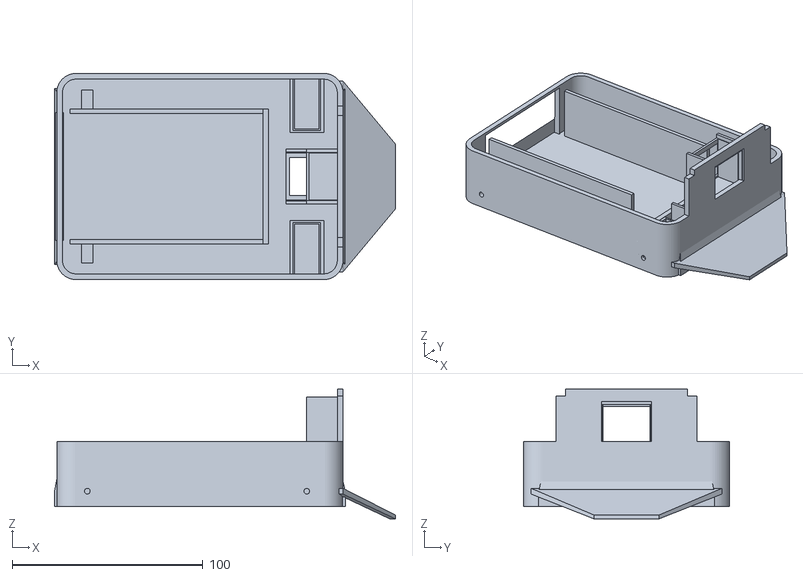
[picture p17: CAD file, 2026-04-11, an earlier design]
hardware/cad/ver1/chassis_n20.stl
178.7 x 108.0 x 68.0

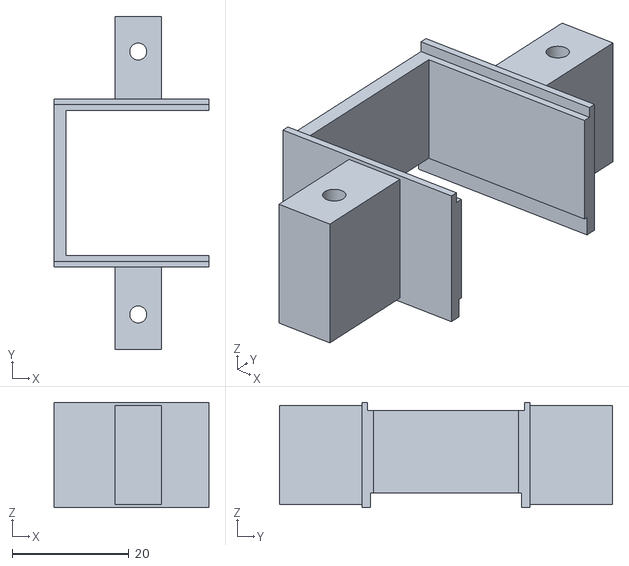
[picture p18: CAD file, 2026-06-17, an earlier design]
hardware/cad/ver1/output/chassis_n20_printable_front_sensor_mount.stl
26.5 x 57.0 x 18.0

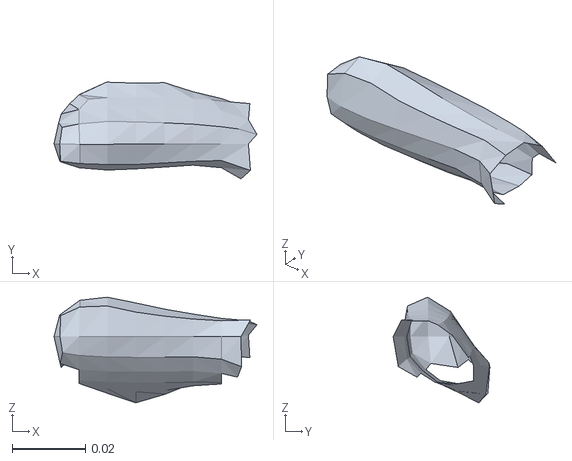
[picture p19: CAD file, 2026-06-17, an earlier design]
hardware/cad/ver2/parts/loose_component_03.stl
0.0554 x 0.0264 x 0.0288

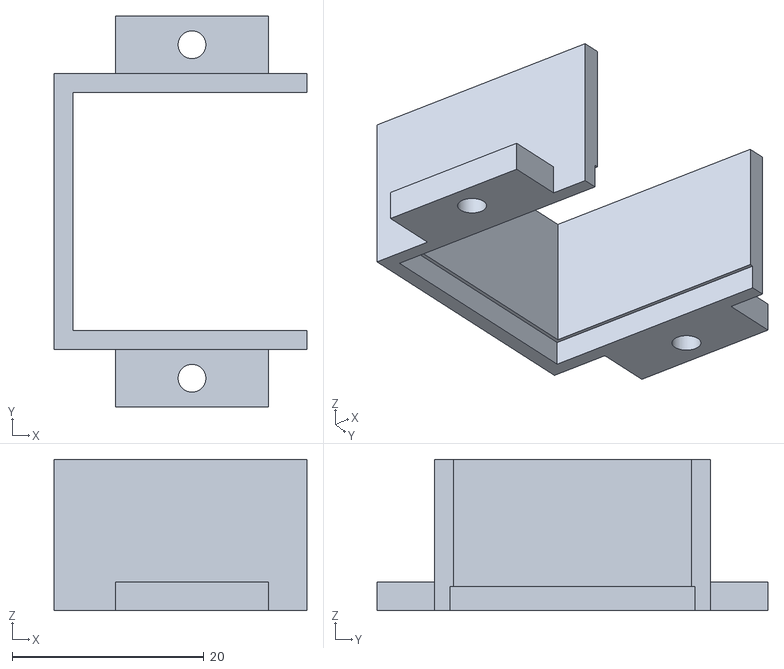
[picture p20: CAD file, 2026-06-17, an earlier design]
hardware/cad/ver1/output/chassis_n20_printable_down_camera_mount.stl
26.4 x 40.8 x 15.8

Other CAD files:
hardware/cad/ver2/parts/rear_half.stl
hardware/cad/ver2/parts/loose_component_01.stl
hardware/cad/ver2/parts/front_left_quadrant.stl
hardware/cad/ver2/parts/loose_component_02.stl
hardware/cad/ver3/korpus_purewhite_hq_4view_00001.scad
hardware/cad/ver1/chassis_n20_printable_front_sensor_mount.scad
hardware/cad/ver1/output/chassis_n20_printable_front_sensor_mount.scad
hardware/cad/ver1/chassis_n20.scad
hardware/cad/real/3D_1-PCB_PCB_ATOM_SUMO_2026-04-14.f3d
hardware/cad/real/3rdfloor.f3d
hardware/cad/real/Assembly new.f3z
hardware/cad/real/Base 1.f3d
hardware/cad/real/Battery pack.f3d
hardware/cad/real/Cilinder.f3d
hardware/cad/real/External1.f3d
hardware/cad/real/External2.f3d
hardware/cad/real/External3.f3d
hardware/cad/real/External4.f3d
hardware/cad/real/External5.f3d
hardware/cad/real/Floor.f3d
hardware/cad/real/Katus.f3d
hardware/cad/real/M5 ATOM Lite.f3d
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

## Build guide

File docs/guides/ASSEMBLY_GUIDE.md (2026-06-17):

# Assembly Guide

This is the current assembly guide for the `ATOM Sumo` prototype.

Status:
- repository assembly documentation is present as a technical checklist;
- current photo evidence is now indexed in [docs/assets/photos](../assets/photos);
- final service/endurance measurements are still required for a true production-ready release.

## Required Reference Files

- [BOM.csv](../specification/BOM.csv)
- [power_scheme.md](../specification/power_scheme.md)
- [hardware/pcb/README.md](../../hardware/pcb/README.md)
- [hardware/cad/real/README.md](../../hardware/cad/real/README.md)

## Main Hardware Blocks

- `M5 ATOM` main controller
- `2 x M5 AtomS3R-CAM`
- `TB6612FNG` motor driver
- `4 x N20 6V` DC gearmotors
- `2S 18650` battery pack
- `2S BMS`
- `5.0V` buck converter for logic
- `6.0V` buck converter for motors
- `VL53L0X` front distance sensor
- `TCS34725` color sensor on Cam 2 Grove I2C
- custom PCB / wiring harness
- printed chassis/enclosure parts

## Mechanical Assembly Order

1. Inspect the real Fusion CAD package:
   - [Robot.f3d](../../hardware/cad/real/Robot.f3d)
   - [Assembly new.f3z](<../../hardware/cad/real/Assembly new.f3z>)
   - [Shell.f3d](../../hardware/cad/real/Shell.f3d)
   - [Topcover.f3d](../../hardware/cad/real/Topcover.f3d)
   - [Battery pack.f3d](<../../hardware/cad/real/Battery pack.f3d>)
2. Print or inspect the chassis/enclosure parts.
3. Install the four N20 motors.
4. Install all four driven wheels.
5. Mount the `2S 18650` battery holder or pack.
6. Mount the main controller and hardware/pcb/body holder.
7. Mount the front `VL53L0X` sensor so it has a clear forward view.
8. Mount Cam 1 as the front/operator camera.
9. Mount Cam 2 upward.
10. Mount the `TCS34725` sensor on Cam 2 Grove I2C so it sees the floor.
11. Verify that no wires touch the wheels or motor shafts.

## Electrical Assembly Order

1. Build the power chain according to [power_scheme.md](../specification/power_scheme.md).
2. Confirm common `GND` between:
   - main controller;
   - motor driver;
   - buck converters;
   - sensors;
   - cameras.
3. Set the logic buck to `5.0V` before connecting controllers/cameras.
4. Set the motor buck to `6.0V` before connecting `TB6612FNG VM`.
5. Add the `1000uF / 16V` capacitor near the motor rail.
6. Connect the motor driver to the main controller pins used by [firmware/main/main.ino](../../firmware/main/main.ino).
7. Wire the left-side motor pair in parallel to TB6612 channel A.
8. Wire the right-side motor pair in parallel to TB6612 channel B.
9. Before floor testing, validate current draw because each TB6612 channel now drives two motors.
10. Connect `VL53L0X` to the configured I2C pins in [firmware/main/main.ino](../../firmware/main/main.ino).
11. Connect `TCS34725` to Cam 2 Grove:
   - SDA `G2`
   - SCL `G1`
   - `5V`
   - `GND`

## Bring-Up Checklist

1. Power only the logic rail and confirm `Robot-Control` Wi-Fi appears.
2. Open `http://192.168.4.1`.
3. Confirm `/tof` responds.
4. Power Cam 1 and confirm `http://192.168.4.20/stream`.
5. Power Cam 2 and confirm `http://192.168.4.21/stream`.
6. Confirm Cam 2 color endpoint: `http://192.168.4.21:81/color`.
7. Test motors on a raised stand before placing the robot on the floor.
8. Test `stop` before any high-speed movement.

## Photo Evidence

Current evidence links:

- [photo evidence index](../assets/photos/README.md)
- [assembled robot photo](../assets/photos/Image%20%281%29.jpg)
- [electronics bench integration photo](../assets/photos/Mutimedia.jpg)
- [printed enclosure with camera/color-sensor placement](../assets/photos/PXL_20260613_160049625.jpg)
- [3D-printing/fabrication photo](../assets/photos/Image%20%282%29.jpg)

Remaining improvement before claiming production-ready assembly documentation:

- add final front/back/left/right/top photos of the same fully assembled robot;
- add close-up photos for battery access, Cam 1, Cam 2, `TCS34725`, and `VL53L0X`;
- add measured battery service time and repeated match/endurance logs.

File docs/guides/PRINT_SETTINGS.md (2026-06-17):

# Print Settings

This document records the current 3D-printing guidance for the robot chassis/enclosure.

Status:
- CAD evidence is present;
- printed-part photo evidence is present;
- final material-specific heat/impact/endurance validation is still open.

## CAD Sources

Baseline chassis:
- [hardware/cad/ver1](../../hardware/cad/ver1)

Functional enclosure/body:
- [hardware/cad/ver3](../../hardware/cad/ver3)

Real Fusion 360 package:
- [hardware/cad/real/README.md](../../hardware/cad/real/README.md)

## Recommended Starting Settings

These are starting values for prototype prints, not yet final production settings.

| Parameter | Starting value |
| --- | --- |
| Material | PLA or PETG |
| Layer height | `0.20 mm` |
| Wall/perimeter count | `3` |
| Top/bottom layers | `4` |
| Infill | `20-35%` |
| Infill pattern | grid, gyroid, or cubic |
| Nozzle | `0.4 mm` |
| Supports | enable only where camera/sensor openings or overhangs require it |
| Bed adhesion | brim if corners lift |

## Material Notes

PLA:
- easier to print;
- good for first fit checks;
- weaker near heat and impacts.

PETG:
- better toughness;
- better for functional enclosure tests;
- may need slower print speed and more stringing cleanup.

## Required Validation Before Production Claim

1. Print the final body parts.
2. Check that motors and wheels do not rub.
3. Check that camera views are not blocked.
4. Check that `VL53L0X` has a clear front window.
5. Check that the downward `TCS34725` sees the floor reliably.
6. Check that the battery can be removed and reinstalled.
7. Run a `5 min` motor heat test.
8. Run `3-5` controlled impact checks.
9. Run repeated `90 s` match-like endurance tests.

Suggested result files:

- `tests/results/enclosure_heat_test.csv`
- `tests/results/enclosure_impact_test.csv`
- `tests/results/battery_service_test.csv`
- `tests/results/match_endurance_test.csv`

## Photos Still Needed

Current photo evidence:

- [3D-printed part on printer](<../assets/photos/Image.jpg>)
- [printing/fabrication process photo](../assets/photos/Image%20%282%29.jpg)
- [printed enclosure/body with camera and color-sensor placement](../assets/photos/PXL_20260613_160049625.jpg)
- [assembled robot photo](../assets/photos/Image%20%281%29.jpg)

For final production-style documentation, still add:

- support removal / cleanup photos;
- final assembled robot from front, back, left, right, and top;
- measured heat, impact, battery-service, and endurance tables.

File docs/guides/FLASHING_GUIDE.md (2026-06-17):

# Flashing Guide

This guide documents the current firmware flashing workflow.

## Arduino CLI

Known local Arduino CLI path on the development machine:

```powershell
$env:LOCALAPPDATA\Programs\Arduino IDE\resources\app\lib\backend\resources\arduino-cli.exe
```

Check version:

```powershell
& "$env:LOCALAPPDATA\Programs\Arduino IDE\resources\app\lib\backend\resources\arduino-cli.exe" version
```

Verified version during repository review:

```text
arduino-cli 1.2.0
```

## Main Controller Firmware

Folder:
- [main](../../firmware/main)

Board/FQBN:
- `m5stack:esp32:m5stack_atom`

Compile:

```powershell
& "$env:LOCALAPPDATA\Programs\Arduino IDE\resources\app\lib\backend\resources\arduino-cli.exe" compile --fqbn m5stack:esp32:m5stack_atom firmware\main
```

Upload example:

```powershell
& "$env:LOCALAPPDATA\Programs\Arduino IDE\resources\app\lib\backend\resources\arduino-cli.exe" upload -p COM5 --fqbn m5stack:esp32:m5stack_atom firmware\main
```

Notes:
- main controller was previously flashed on `COM5`;
- COM port may change after reconnecting USB.

## Camera Firmware

Folder:
- [firmware/camera/sketch_jan17a](../../firmware/camera/sketch_jan17a)

Board/FQBN:
- `m5stack:esp32:m5stack_atoms3r`

The same camera firmware is used for both cameras. Select the slot at compile time.

### Cam 1

Compile:

```powershell
& "$env:LOCALAPPDATA\Programs\Arduino IDE\resources\app\lib\backend\resources\arduino-cli.exe" compile --fqbn m5stack:esp32:m5stack_atoms3r --build-property build.extra_flags="-DCAMERA_SLOT=1" firmware\camera\sketch_jan17a
```

Expected IP after boot:

```text
http://192.168.4.20/stream
```

### Cam 2

Compile:

```powershell
& "$env:LOCALAPPDATA\Programs\Arduino IDE\resources\app\lib\backend\resources\arduino-cli.exe" compile --fqbn m5stack:esp32:m5stack_atoms3r --build-property build.extra_flags="-DCAMERA_SLOT=2" firmware\camera\sketch_jan17a
```

Upload example:

```powershell
& "$env:LOCALAPPDATA\Programs\Arduino IDE\resources\app\lib\backend\resources\arduino-cli.exe" upload -p COM6 --fqbn m5stack:esp32:m5stack_atoms3r --build-property build.extra_flags="-DCAMERA_SLOT=2" firmware\camera\sketch_jan17a
```

Expected endpoints after boot:

```text
http://192.168.4.21/stream
http://192.168.4.21:81/color
```

Notes:
- Cam 2 was previously flashed on `COM6`;
- Cam 2 contains the `TCS34725` color telemetry path.

## Post-Flash Check

1. Power the main controller.
2. Connect to Wi-Fi SSID `Robot-Control`.
3. Open `http://192.168.4.1`.
4. Confirm the UI loads.
5. Confirm `/tof` returns JSON.
6. Confirm Cam 1 stream.
7. Confirm Cam 2 stream.
8. Confirm Cam 2 color JSON on port `81`.

## Measurement Launchers

After flashing and connecting the laptop to `Robot-Control`, measurements can be started from PowerShell launchers in [tools](../../tools):

- [RUN_MEASUREMENTS.ps1](../../tools/RUN_MEASUREMENTS.ps1) - menu for brownout and ToF accuracy tests.
- [RUN_POWER_BROWNOUT_TEST.ps1](../../tools/RUN_POWER_BROWNOUT_TEST.ps1) - direct brownout test launcher.

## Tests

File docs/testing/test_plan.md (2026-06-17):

# Test Plan

This document summarizes the practical verification plan for the current `ATOM Sumo` prototype.

It is intentionally split into:

- tests already supported by repository evidence;
- tests implemented in firmware but still needing stronger measured evidence;
- tests still required before a true production-ready claim.

## Current Verified Tests

### 1. Wi-Fi Access Point and Web UI

Objective:
- confirm that the robot starts its own Wi-Fi network and serves the control page.

Method:
- power on the main controller;
- verify that SSID `Robot-Control` appears;
- connect a client device;
- open `http://192.168.4.1/`.

Pass condition:
- the AP is visible;
- the web page opens successfully;
- the UI loads without external infrastructure.

Evidence:
- [main firmware](../../firmware/main/main.ino)
- [main web UI](../../firmware/main/01_WebUi.ino)

Status:
- implemented and used as the baseline operator interface.

### 2. Camera Stream Test

Objective:
- confirm that the camera nodes stream video through the robot network.

Method:
- power the `AtomS3R-CAM` node;
- connect it to the robot AP;
- open the stream from the web page or direct stream endpoint;
- visually verify live video.

Pass condition:
- the camera stream loads and updates continuously.

Evidence:
- [camera firmware](../../firmware/camera/sketch_jan17a/sketch_jan17a.ino)
- [camera stream demo video](../../media/video/MicrosoftTeams-video.mp4)

Status:
- camera streaming is implemented for static IP camera nodes `192.168.4.20` and `192.168.4.21`.

### 3. Manual Drive Command Test

Objective:
- verify that the UI can send motion commands to the robot.

Method:
- send `forward`, `backward`, `left`, `right`, diagonal arc commands, and `stop` from the web UI;
- confirm motor response on the robot or raised test stand;
- verify speed control using the UI speed slider.

Pass condition:
- all direction commands are accepted;
- both motor channels respond as expected;
- stop command always works.

Evidence:
- [main firmware](../../firmware/main/main.ino)
- [motion logic](../../firmware/main/02_Motion.ino)
- [web handlers](../../firmware/main/03_WebHandlers.ino)

Status:
- implemented and used for movement measurements.

### 4. HTTP Latency Test

Objective:
- measure command-path responsiveness of the robot control interface.

Method:
- run the latency script against `http://192.168.4.1`;
- alternate `/move?dir=forward` and `/move?dir=stop`;
- collect `120` requests per run;
- compare `speed=0` and `speed=180` runs.

Pass condition:
- median latency is within a usable range for manual control;
- stop latency remains stable;
- results are recorded for reporting.

Evidence:
- [latency test script](../../tests/scripts/http_latency_test.py)
- [power brownout test script](../../tests/scripts/power_brownout_test.py)
- [ToF accuracy collection script](../../tests/scripts/tof_accuracy_collect.py)
- [latency analysis notebook](../../tests/notebooks/http_latency_analysis.ipynb)
- [latency result write-up](latency_test_result.md)
- [analysis results folder](../../tests/results)

Status:
- measured and documented.

### 5. Movement Speed Test

Objective:
- measure how fast the robot travels at different PWM values.

Method:
- mark a straight `1.0 m` distance;
- command `forward`;
- measure travel time;
- calculate `speed_m_s = distance_m / time_s`.

Evidence:
- [movement_speed_test.csv](../../tests/results/movement_speed_test.csv)

Status:
- measured for PWM `80`, `150`, `180`, and `255`.

### 6. Straightness / Drift Test

Objective:
- measure whether the robot drives straight or pulls left/right.

Method:
- drive forward over `1.0 m`;
- measure lateral offset at the finish.

Evidence:
- [movement_drift_test.csv](../../tests/results/movement_drift_test.csv)

Status:
- measured; drift is mostly left and should be used for motor trim calibration.

### 7. Turn-In-Place Test

Objective:
- measure turning response for left and right commands.

Method:
- command `left` or `right`;
- measure time for `180 deg` turns;
- repeat for both directions.

Evidence:
- [movement_turn_test.csv](../../tests/results/movement_turn_test.csv)

Status:
- measured for PWM `150`, `180`, and `255`.

### 8. ToF Stop Behavior Test

Objective:
- verify that the `VL53L0X` safety stop can stop the robot before an obstacle.

Method:
- set ToF stop threshold values such as `400 mm`, `300 mm`, and `250 mm`;
- drive toward an obstacle at several PWM values;
- record the actual stop distance and result.

Evidence:
- [tof_stop_test.csv](../../tests/results/tof_stop_test.csv)

Status:
- measured; works at moderate speeds, but high-speed PWM `255` requires tuning.

### 9. Cam 2 Color Sensor Integration Test

Objective:
- verify that the downward `TCS34725` sensor connected to Cam 2 returns live color data.

Method:
- flash Cam 2 with `CAMERA_SLOT=2`;
- open `http://192.168.4.21:81/color`;
- verify that JSON updates;
- verify that the main UI color panel updates.

Pass condition:
- endpoint returns `ready:true`;
- UI shows color name and RGB/clear values;
- stream on port `80` remains usable while color telemetry is served on port `81`.

Evidence:
- [camera firmware](../../firmware/camera/sketch_jan17a/sketch_jan17a.ino)
- [main web UI](../../firmware/main/01_WebUi.ino)

Status:
- implemented, flashed, and measured on red, light, and dark surfaces. Closed-loop retreat/avoid behavior is not claimed in this test.

### 10. Tap-Drive and Simple Auto Behavior

Objective:
- verify that the UI contains higher-level control modes beyond manual driving.

Method:
- enable tap-drive and tap the front camera view;
- enable auto mode and verify ToF-based movement decisions.

Evidence:
- [main web UI](../../firmware/main/01_WebUi.ino)
- [auto behavior logger](auto_behavior_logger.md)
- [auto behavior observation](auto_behavior_observation.md)
- [tap-drive algorithm](tap_drive_algorithm.md)
- [camera calibration and tap-drive plan](camera_calibration_tap_drive_plan.md)
- [camera calibration notebook](../../tests/notebooks/camera_calibration_tap_drive.ipynb)
- [tap-drive accuracy template](../../tests/results/tap_drive_accuracy_test_template.csv)

Status:
- implemented as a timed camera-coordinate tap-drive algorithm.
- not yet calibrated with full OpenCV/homography.
- not yet measured against target accuracy requirements.

## Open Tests Required for Stronger V3-V5 Claims

### A. Static ToF Accuracy

Current file:
- [tof_accuracy_test.csv](../../tests/results/tof_accuracy_test.csv)

Current status:
- measured rows exist in [tof_accuracy_test.csv](../../tests/results/tof_accuracy_test.csv);
- readings show a large offset/error at several distances, so calibration or mounting explanation is still required.

Required measurements:
- actual distances: `50`, `100`, `200`, `300`, and `500 mm`;
- at least `3` trials per distance;
- record `measured_mm`, `status`, and `error_mm`.

### B. Power Brownout / Reset Test

Current file:
- [power_brownout_test.csv](../../tests/results/power_brownout_test.csv)

Current status:
- measured rows exist in [power_brownout_test.csv](../../tests/results/power_brownout_test.csv);
- no main-controller reset or Wi-Fi disconnect was observed in the current run;
- Cam1/Cam2 endpoint failures were recorded, so the test must be repeated with both camera nodes confirmed online.

Required measurements:
- repeat PWM `80`, `150`, `180`, and `255`;
- repeat commands `forward`, `backward`, `left`, `right`, and `stop`;
- record reset, Wi-Fi disconnect, camera loss, and notes for both camera nodes.

### C. Color / Red-Area Repeatability

Current file:
- [color_repeatability_test.csv](../../tests/results/color_repeatability_test.csv)

Current status:
- measured rows exist for red, light, and dark surfaces;
- dark threshold was corrected and flashed to Cam 2;
- UI confirmed `COLOR DARK` after the fix.

### D. Click-To-Drive Accuracy

Required measurements:
- mark target points on the arena;
- tap camera image;
- measure final target error in `mm` and heading error in `deg`;
- repeat at least `5-10` trials.

Suggested output:
- template: [tap_drive_accuracy_test_template.csv](../../tests/results/tap_drive_accuracy_test_template.csv)
- measured output after testing: `tests/results/tap_drive_accuracy_test.csv`

### E. Enclosure and Service Tests

Required measurements:
- motor/enclosure heat after `5 min` driving;
- `3-5` controlled impact checks;
- battery replacement/service time;
- repeated `90 s` match-like endurance runs.

Suggested outputs:
- `tests/results/enclosure_heat_test.csv`
- `tests/results/enclosure_impact_test.csv`
- `tests/results/battery_service_test.csv`
- `tests/results/match_endurance_test.csv`

## Recommended Defense Wording

The project has verified the control path, web UI, camera streaming, movement, ToF stop behavior, and Cam 2 color telemetry. The remaining validation work is no longer basic bring-up; it is calibration, repeatability, enclosure validation, power robustness, and production documentation.

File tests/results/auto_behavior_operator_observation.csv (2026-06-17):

date | trial | obstacle_distance_mm | observed_action | result | source | notes
2026-06-17 | 1 | 200 | turn_or_avoid | pass | operator_observation | Robot was observed turning/avoiding at approximately 20 cm; battery depleted before a full 5-trial logger CSV could be collected.

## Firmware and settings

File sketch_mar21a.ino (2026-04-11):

#include <WiFi.h>
#include <WebServer.h>
#include <DNSServer.h>

#define PWMA 22
#define AIN1 19
#define AIN2 23

#define PWMB 25
#define BIN1 21
#define BIN2 33
#define ATOM_LED_PIN 27

const char *AP_SSID = "Robot-Control";
const char *AP_PASSWORD = "robot123";

WebServer server(80);
DNSServer dnsServer;
const uint16_t DNS_PORT = 53;

enum MotionDirection {
  DIR_STOP,
  DIR_FORWARD,
  DIR_BACKWARD,
  DIR_LEFT,
  DIR_RIGHT
};

MotionDirection currentDirection = DIR_STOP;
uint8_t motorSpeed = 180;
bool standbyBlinkOn = false;
unsigned long lastStandbyBlinkMs = 0;

// Forward on many small robots can overload one side at max PWM.
// Keep A slightly prioritized and give both motors a short start boost.
const uint8_t MOTOR_A_FORWARD_TRIM = 255;
const uint8_t MOTOR_B_FORWARD_TRIM = 255;
const uint8_t MOTOR_A_BACKWARD_TRIM = 255;
const uint8_t MOTOR_B_BACKWARD_TRIM = 255;
const uint8_t START_BOOST_PWM = 255;
const uint16_t START_BOOST_MS = 120;
const uint16_t STANDBY_BLINK_INTERVAL_MS = 450;
const uint8_t LED_BRIGHTNESS = 110;
const bool MOTOR_A_FORWARD_PWM_INVERTED = true;
const bool MOTOR_A_BACKWARD_PWM_INVERTED = false;
const bool MOTOR_A_LEFT_TURN_PWM_INVERTED = false;
const bool MOTOR_A_RIGHT_TURN_PWM_INVERTED = true;

const char INDEX_HTML[] PROGMEM = R"rawliteral(
<!DOCTYPE html>
<html lang="en">
<head>
  <meta charset="UTF-8" />
  <meta name="viewport" content="width=device-width, initial-scale=1.0" />
  <title>Robot Control</title>
  <style>
    :root {
      --bg-a: #0f172a;
      --bg-b: #1d4e89;
      --panel: #ffffff;
      --ink: #0b1f33;
      --btn: #0ea5e9;
      --btn-active: #0369a1;
      --btn-stop: #ef4444;
      --btn-stop-active: #b91c1c;
    }

    * {
      box-sizing: border-box;
      -webkit-tap-highlight-color: transparent;
      font-family: "Segoe UI", "Trebuchet MS", sans-serif;
    }

    body {
      margin: 0;
      min-height: 100vh;
      display: grid;
      place-items: center;
      background: radial-gradient(circle at 20% 20%, #3b82f6 0%, var(--bg-b) 35%, var(--bg-a) 100%);
      color: var(--ink);
      padding: 16px;
    }

    .card {
      width: min(480px, 100%);
      background: var(--panel);
      border-radius: 20px;
      box-shadow: 0 16px 40px rgba(2, 6, 23, 0.35);
      padding: 18px;
    }

    h1 {
      margin: 0 0 6px;
      font-size: 1.4rem;
      text-align: center;
    }

    .hint {
      margin: 0 0 14px;
      text-align: center;
      color: #334155;
      font-size: 0.95rem;
    }

    .cams {
      display: grid;
      grid-template-columns: 1fr;
      gap: 10px;
      margin-bottom: 14px;
    }

    .cam-card {
      background: #0b1f33;
      border-radius: 14px;
      padding: 8px;
      color: #cbd5e1;
    }

    .cam-head {
      display: flex;
      justify-content: space-between;
      align-items: center;
      font-size: 0.8rem;
      font-weight: 700;
      margin: 0 3px 6px;
      letter-spacing: 0.03em;
    }

    .cam-state {
      font-size: 0.75rem;
      opacity: 0.9;
      text-transform: uppercase;
    }

    .cam-card img {
      width: 100%;
      aspect-ratio: 4 / 3;
      object-fit: cover;
      border-radius: 10px;
      background: #020617;
      display: block;
    }

    .pad {
      display: grid;
      grid-template-columns: repeat(3, 1fr);
      grid-template-areas:
        ". up ."
        "left stop right"
        ". down .";
      gap: 12px;
      margin-bottom: 16px;
    }

    button,
    .ctrl-btn {
      border: none;
      border-radius: 16px;
      min-height: 82px;
      font-size: 1.05rem;
      font-weight: 700;
      color: #fff;
      background: var(--btn);
      box-shadow: 0 8px 18px rgba(14, 165, 233, 0.35);
      transition: transform 0.08s ease, background 0.08s ease;
      touch-action: manipulation;
      user-select: none;
      display: flex;
      align-items: center;
      justify-content: center;
      text-decoration: none;
      text-align: center;
    }

    .pad button {
      touch-action: none;
    }

    button:active,
    button.active,
    .ctrl-btn:active {
      transform: scale(0.97);
      background: var(--btn-active);
    }

    #up { grid-area: up; }
    #left { grid-area: left; }
    #right { grid-area: right; }
    #down { grid-area: down; }
    #stop {
      grid-area: stop;
      background: var(--btn-stop);
      box-shadow: 0 8px 18px rgba(239, 68, 68, 0.35);
    }

    #stop:active,
    #stop.active {
      background: var(--btn-stop-active);
    }

    .speed-box {
      background: #f1f5f9;
      border-radius: 14px;
      padding: 12px;
    }

    .speed-row {
      display: flex;
      justify-content: space-between;
      align-items: center;
      margin-bottom: 8px;
      font-weight: 700;
    }

    input[type="range"] {
      width: 100%;
      accent-color: #0284c7;
    }

    .footer {
      margin-top: 12px;
      text-align: center;
      color: #64748b;
      font-size: 0.85rem;
    }

    @media (min-width: 760px) {
      .card {
        width: min(860px, 100%);
      }

      .cams {
        grid-template-columns: 1fr 1fr;
      }
    }
  </style>
</head>
<body>
  <main class="card">
    <h1>Robot Control</h1>
    <section class="cams">
      <article class="cam-card">
        <div class="cam-head">
          <span>CAM 1</span>
          <span class="cam-state">live</span>
        </div>
        <img src="http://192.168.4.20/stream" alt="Camera 1 stream" />
      </article>
      <article class="cam-card">
        <div class="cam-head">
          <span>CAM 2</span>
          <span class="cam-state">live</span>
        </div>
        <img src="http://192.168.4.21/stream" alt="Camera 2 stream" />
      </article>
    </section>
    <p class="hint">Hold a direction button to move. Release to stop.</p>

    <section class="pad">
      <button type="button" id="up">FORWARD</button>
      <button type="button" id="left">LEFT</button>
      <button type="button" id="stop">STOP</button>
      <button type="button" id="right">RIGHT</button>
      <button type="button" id="down">BACK</button>
    </section>

    <section class="speed-box">
      <div class="speed-row">
        <span>Speed</span>
        <span><strong id="speedValue">180</strong> / 255</span>
      </div>
      <input id="speed" name="value" type="range" min="0" max="255" value="180" />
    </section>

    <p class="footer">AP: Robot-Control (192.168.4.1) | Cam1: 192.168.4.20 | Cam2: 192.168.4.21 | Build: R2026-03-28-3</p>
  </main>
  <script>
    (function () {
      var speedInput = document.getElementById("speed");
      var speedValue = document.getElementById("speedValue");
      var stopButton = document.getElementById("stop");
      var hasPointer = !!window.PointerEvent;
      var holdButtons = [
        { id: "up", dir: "forward" },
        { id: "down", dir: "backward" },
        { id: "left", dir: "left" },
        { id: "right", dir: "right" }
      ];
      var activeDirection = "stop";
      var speedTimer = null;
      var activeHoldButtonId = null;
      var activePointerId = null;
      var ignoreMouseUntil = 0;

      function send(path) {
        if (window.fetch) {
          fetch(path, { cache: "no-store" }).catch(function () {});
        } else {
          var beacon = new Image();
          beacon.src = path + "&_ts=" + Date.now();
        }
      }

      function setActiveButton(id) {
        var buttons = document.querySelectorAll(".pad button");
        for (var i = 0; i < buttons.length; i++) {
          buttons[i].classList.remove("active");
        }
        if (!id) {
          return;
        }
        var selected = document.getElementById(id);
        if (selected) {
          selected.classList.add("active");
        }
      }

      function move(dir, buttonId) {
        if (activeDirection === dir && activeHoldButtonId === buttonId) {
          return;
        }
        activeDirection = dir;
        activeHoldButtonId = buttonId;
        setActiveButton(buttonId);
        send("/move?dir=" + dir);
      }

      function stop() {
        if (activeDirection === "stop") {
          return;
        }
        activeDirection = "stop";
        activeHoldButtonId = null;
        activePointerId = null;
        setActiveButton("stop");
        send("/move?dir=stop");
      }

      function bindHold(buttonId, dir) {
        var button = document.getElementById(buttonId);
        if (!button) {
          return;
        }

        function startMove(e) {
          if (e.cancelable) {
            e.preventDefault();
          }
          move(dir, buttonId);
        }

        function endMove(e) {
          if (e && e.cancelable) {
            e.preventDefault();
          }
          if (activeHoldButtonId === buttonId) {
            stop();
          }
        }

        if (hasPointer) {
          button.addEventListener("pointerdown", function (e) {
            if (e.button !== undefined && e.button !== 0) {
              return;
            }
            if (activePointerId !== null && activePointerId !== e.pointerId) {
              return;
            }
            activePointerId = e.pointerId;
            if (typeof button.setPointerCapture === "function") {
              try {
                button.setPointerCapture(e.pointerId);
              } catch (err) {}
            }
            startMove(e);
          });

          button.addEventListener("pointerup", function (e) {
            if (activePointerId === e.pointerId) {
              endMove(e);
            }
          });

          button.addEventListener("pointercancel", function (e) {
            if (activePointerId === e.pointerId) {
              endMove(e);
            }
          });

          button.addEventListener("lostpointercapture", function () {
            if (activeHoldButtonId === buttonId) {
              stop();
            }
          });
          return;
        }

        button.addEventListener("touchstart", function (e) {
          ignoreMouseUntil = Date.now() + 700;
          startMove(e);
        }, { passive: false });
        button.addEventListener("touchend", endMove, { passive: false });
        button.addEventListener("touchcancel", endMove, { passive: false });

        button.addEventListener("mousedown", function (e) {
          if (Date.now() < ignoreMouseUntil) {
            return;
          }
          if (e.button !== undefined && e.button !== 0) {
            return;
          }
          startMove(e);
        });
        button.addEventListener("mouseup", endMove);
        button.addEventListener("mouseleave", function (e) {
          if (e.buttons === 0) {
            endMove(e);
          }
        });
      }

      for (var j = 0; j < holdButtons.length; j++) {
        bindHold(holdButtons[j].id, holdButtons[j].dir);
      }

      if (stopButton) {
        if (hasPointer) {
          stopButton.addEventListener("pointerdown", function (e) {
            if (e.cancelable) {
              e.preventDefault();
            }
            stop();
          });
        } else {
          stopButton.addEventListener("click", function (e) {
            e.preventDefault();
            stop();
          });
        }
      }

      if (speedInput) {
        speedInput.addEventListener("input", function () {
          if (speedValue) {
            speedValue.textContent = speedInput.value;
          }
          if (speedTimer) {
            clearTimeout(speedTimer);
          }
          speedTimer = setTimeout(function () {
            send("/speed?value=" + encodeURIComponent(speedInput.value));
          }, 120);
        });
      }

      if (hasPointer) {
        document.addEventListener("pointerup", function (e) {
          if (activePointerId === e.pointerId) {
            stop();
          }
        });
        document.addEventListener("pointercancel", function (e) {
          if (activePointerId === e.pointerId) {
            stop();
          }
        });
      } else {
        document.addEventListener("touchend", function () {
          if (activeHoldButtonId) {
            stop();
          }
        }, { passive: false });
      }

      document.addEventListener("visibilitychange", function () {
        if (document.hidden) {
          stop();
        }
      });

      window.addEventListener("blur", function () {
        stop();
      });

      window.addEventListener("beforeunload", function () {
        stop();
      });

      setActiveButton("stop");
    })();
  </script>
</body>
</html>
)rawliteral";

void setMotorA(int direction, uint8_t pwm) {
  if (direction > 0) {
    digitalWrite(AIN1, HIGH);
    digitalWrite(AIN2, LOW);
    analogWrite(PWMA, pwm);
  } else if (direction < 0) {
    digitalWrite(AIN1, LOW);
    digitalWrite(AIN2, HIGH);
    analogWrite(PWMA, pwm);
  } else {
    analogWrite(PWMA, 0);
    digitalWrite(AIN1, LOW);
    digitalWrite(AIN2, LOW);
  }
}

void setMotorB(int direction, uint8_t pwm) {
  if (direction > 0) {
    digitalWrite(BIN1, HIGH);
    digitalWrite(BIN2, LOW);
    analogWrite(PWMB, pwm);
  } else if (direction < 0) {
    digitalWrite(BIN1, LOW);
    digitalWrite(BIN2, HIGH);
    analogWrite(PWMB, pwm);
  } else {
    analogWrite(PWMB, 0);
    digitalWrite(BIN1, LOW);
    digitalWrite(BIN2, LOW);
  }
}

uint8_t applyTrim(uint8_t baseSpeed, uint8_t trim) {
  return static_cast<uint8_t>((static_cast<uint16_t>(baseSpeed) * trim) / 255);
}

uint8_t maybeInvertPwm(uint8_t pwm, bool inverted) {
  return inverted ? static_cast<uint8_t>(255 - pwm) : pwm;
}

void setAtomLed(uint8_t r, uint8_t g, uint8_t b) {
  uint8_t rr = static_cast<uint8_t>((static_cast<uint16_t>(r) * LED_BRIGHTNESS) / 255);
  uint8_t gg = static_cast<uint8_t>((static_cast<uint16_t>(g) * LED_BRIGHTNESS) / 255);
  uint8_t bb = static_cast<uint8_t>((static_cast<uint16_t>(b) * LED_BRIGHTNESS) / 255);
  rgbLedWrite(ATOM_LED_PIN, rr, gg, bb);
}

void applyDirectionLed(MotionDirection dir) {
  switch (dir) {
    case DIR_FORWARD:
      standbyBlinkOn = false;
      setAtomLed(0, 255, 0);      // Green
      break;
    case DIR_BACKWARD:
      standbyBlinkOn = false;
      setAtomLed(255, 0, 0);      // Red
      break;
    case DIR_LEFT:
      standbyBlinkOn = false;
      setAtomLed(160, 0, 255);    // Violet
      break;
    case DIR_RIGHT:
      standbyBlinkOn = false;
      setAtomLed(255, 120, 0);    // Orange
      break;
    case DIR_STOP:
    default:
      standbyBlinkOn = true;
      lastStandbyBlinkMs = millis();
      setAtomLed(0, 0, 255);      // Blue blink starts "ON"
      break;
  }
}

void updateStandbyLedBlink() {
  if (!standbyBlinkOn || currentDirection != DIR_STOP) {
    return;
  }

  unsigned long now = millis();
  if (now - lastStandbyBlinkMs < STANDBY_BLINK_INTERVAL_MS) {
    return;
  }

  lastStandbyBlinkMs = now;
  static bool phaseOn = true;
  phaseOn = !phaseOn;
  if (phaseOn) {
    setAtomLed(0, 0, 255);
  } else {
    setAtomLed(0, 0, 0);
  }
}

void moveWithBoost(int dirA, uint8_t pwmA, int dirB, uint8_t pwmB, bool useBoost) {
  if (useBoost && (pwmA > 0 || pwmB > 0)) {
    setMotorA(dirA, max(pwmA, START_BOOST_PWM));
    setMotorB(dirB, max(pwmB, START_BOOST_PWM));
    delay(START_BOOST_MS);
  }

  setMotorA(dirA, pwmA);
  setMotorB(dirB, pwmB);
}

void applyDirection(MotionDirection dir) {
  MotionDirection previousDirection = currentDirection;
  currentDirection = dir;
  bool fromStop = (previousDirection == DIR_STOP && dir != DIR_STOP);

  if (previousDirection != DIR_STOP && dir != DIR_STOP && previousDirection != dir) {
    setMotorA(0, 0);
    setMotorB(0, 0);
    delay(40);
  }

  switch (dir) {
    case DIR_FORWARD:
      moveWithBoost(
        1,
        maybeInvertPwm(applyTrim(motorSpeed, MOTOR_A_FORWARD_TRIM), MOTOR_A_FORWARD_PWM_INVERTED),
        1,
        applyTrim(motorSpeed, MOTOR_B_FORWARD_TRIM),
        fromStop
      );
      break;
    case DIR_BACKWARD:
      moveWithBoost(
        -1,
        maybeInvertPwm(applyTrim(motorSpeed, MOTOR_A_BACKWARD_TRIM), MOTOR_A_BACKWARD_PWM_INVERTED),
        -1,
        applyTrim(motorSpeed, MOTOR_B_BACKWARD_TRIM),
        fromStop
      );
      break;
    case DIR_LEFT:
      moveWithBoost(
        -1,
        maybeInvertPwm(motorSpeed, MOTOR_A_LEFT_TURN_PWM_INVERTED),
        1,
        motorSpeed,
        fromStop
      );
      break;
    case DIR_RIGHT:
      moveWithBoost(
        1,
        maybeInvertPwm(motorSpeed, MOTOR_A_RIGHT_TURN_PWM_INVERTED),
        -1,
        motorSpeed,
        fromStop
      );
      break;
    case DIR_STOP:
    default:
      setMotorA(0, 0);
      setMotorB(0, 0);
      break;
  }

  applyDirectionLed(dir);
}

void handleRoot() {
  server.sendHeader("Cache-Control", "no-store, no-cache, must-revalidate, max-age=0");
  server.sendHeader("Pragma", "no-cache");
  server.sendHeader("Expires", "0");
  server.send_P(200, "text/html", INDEX_HTML);
}

void redirectToPortal(uint16_t code = 302) {
  String portalUrl = String("http://") + WiFi.softAPIP().toString() + "/";
  server.sendHeader("Location", portalUrl, true);
  server.send(code, "text/plain", "");
}

void redirectToRoot() {
  server.sendHeader("Location", "/", true);
  server.send(303, "text/plain", "");
}

void handleCaptiveProbe() {
  redirectToPortal(302);
}

void handleNotFound() {
  redirectToPortal(302);
}

void handleMove() {
  if (!server.hasArg("dir")) {
    server.send(400, "text/plain", "Missing dir");
    return;
  }

  String dir = server.arg("dir");

  if (dir == "forward") {
    applyDirection(DIR_FORWARD);
  } else if (dir == "backward") {
    applyDirection(DIR_BACKWARD);
  } else if (dir == "left") {
    applyDirection(DIR_LEFT);
  } else if (dir == "right") {
    applyDirection(DIR_RIGHT);
  } else if (dir == "stop") {
    applyDirection(DIR_STOP);
  } else {
    server.send(400, "text/plain", "Invalid dir");
    return;
  }

  if (server.hasArg("ui")) {
    redirectToRoot();
    return;
  }

  server.send(200, "text/plain", "OK");
}

void handleSpeed() {
  if (!server.hasArg("value")) {
    server.send(400, "text/plain", "Missing value");
    return;
  }

  int value = constrain(server.arg("value").toInt(), 0, 255);
  motorSpeed = static_cast<uint8_t>(value);

  if (currentDirection != DIR_STOP) {
    applyDirection(currentDirection);
  }

  if (server.hasArg("ui")) {
    redirectToRoot();
    return;
  }

  server.send(200, "text/plain", String(motorSpeed));
}

void setup() {
  Serial.begin(115200);

  pinMode(PWMA, OUTPUT);
  pinMode(AIN1, OUTPUT);
  pinMode(AIN2, OUTPUT);
  pinMode(PWMB, OUTPUT);
  pinMode(BIN1, OUTPUT);
  pinMode(BIN2, OUTPUT);
  pinMode(ATOM_LED_PIN, OUTPUT);

  applyDirection(DIR_STOP);

  WiFi.mode(WIFI_AP);
  bool apStarted = WiFi.softAP(AP_SSID, AP_PASSWORD, 1, 0, 8);

  dnsServer.start(DNS_PORT, "*", WiFi.softAPIP());

  server.on("/", handleRoot);
  server.on("/move", HTTP_GET, handleMove);
  server.on("/speed", HTTP_GET, handleSpeed);
  server.on("/generate_204", HTTP_GET, handleCaptiveProbe);       // Android
  server.on("/gen_204", HTTP_GET, handleCaptiveProbe);            // Android alt
  server.on("/hotspot-detect.html", HTTP_GET, handleCaptiveProbe); // iOS/macOS
  server.on("/library/test/success.html", HTTP_GET, handleCaptiveProbe); // iOS
  server.on("/connecttest.txt", HTTP_GET, handleCaptiveProbe);    // Windows
  server.on("/ncsi.txt", HTTP_GET, handleCaptiveProbe);           // Windows
  server.on("/fwlink", HTTP_GET, handleCaptiveProbe);             // Windows
  server.onNotFound(handleNotFound);
  server.begin();

  Serial.println();
  Serial.println("=== Robot AP mode ===");
  Serial.printf("AP started: %s\n", apStarted ? "YES" : "NO");
  Serial.printf("SSID: %s\n", AP_SSID);
  Serial.printf("Password: %s\n", AP_PASSWORD);
  Serial.printf("Open: http://%s\n", WiFi.softAPIP().toString().c_str());
}

void loop() {
  dnsServer.processNextRequest();
  server.handleClient();
  updateStandbyLedBlink();
}

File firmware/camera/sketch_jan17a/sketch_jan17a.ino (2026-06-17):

/*
 * AtomS3R-CAM brighter stream
 * Goal: brighter image first, with higher FPS and no obvious quality loss
 * on a sensor that does not support native JPEG output.
 */

#ifndef _M5_ATOM_S3R_CAM_H_
#define _M5_ATOM_S3R_CAM_H_

#define PWDN_GPIO_NUM  -1
#define RESET_GPIO_NUM -1
#define XCLK_GPIO_NUM  21
#define SIOD_GPIO_NUM  12
#define SIOC_GPIO_NUM  9
#define Y9_GPIO_NUM    13
#define Y8_GPIO_NUM    11
#define Y7_GPIO_NUM    17
#define Y6_GPIO_NUM    4
#define Y5_GPIO_NUM    48
#define Y4_GPIO_NUM    46
#define Y3_GPIO_NUM    42
#define Y2_GPIO_NUM    3
#define VSYNC_GPIO_NUM 10
#define HREF_GPIO_NUM  14
#define PCLK_GPIO_NUM  40
#define POWER_GPIO_NUM 18

#endif

#include <WiFi.h>
#include <Wire.h>
#include <cstring>
#include "esp_camera.h"
#include "freertos/FreeRTOS.h"
#include "freertos/semphr.h"
#include "freertos/task.h"

#define USE_ATOMS3R_CAM
#define STA_MODE

#ifndef CAMERA_SLOT
// Set to 1 for first camera board, 2 for second camera board.
#define CAMERA_SLOT 2
#endif

#if (CAMERA_SLOT != 1) && (CAMERA_SLOT != 2)
#error "CAMERA_SLOT must be 1 or 2"
#endif

const char* ssid = "Robot-Control";
const char* password = "robot123";
const char* CAMERA_NAME = (CAMERA_SLOT == 1) ? "cam1" : "cam2";
const uint8_t CAMERA_IP_LAST_OCTET = (CAMERA_SLOT == 1) ? 20 : 21;

WiFiServer server(80);
WiFiServer colorServer(81);

static const uint16_t STREAM_CHUNK_BYTES = 16 * 1024;
static const uint8_t JPEG_QUALITY_STREAM = 72;
static const uint8_t JPEG_QUALITY_CAPTURE = 82;
static const size_t HTTP_LINE_BYTES = 256;
static const size_t STREAM_JPEG_BUFFER_BYTES = 32 * 1024;
static const size_t STREAM_FRAME_BUFFER_BYTES = 64 * 1024;
static const framesize_t STREAM_FRAME_SIZE = FRAMESIZE_QVGA;
static const uint32_t REQUEST_START_TIMEOUT_MS = 1000;
static const uint32_t HTTP_LINE_TIMEOUT_MS = 1000;
static const uint8_t HTTP_MAX_HEADER_LINES = 40;
static const BaseType_t STREAM_CAPTURE_CORE = 0;

static const uint8_t COLOR_SENSOR_SDA_PIN = 2;
static const uint8_t COLOR_SENSOR_SCL_PIN = 1;
static const uint8_t TCS34725_ADDR = 0x29;
static const uint8_t TCS34725_COMMAND_BIT = 0x80;
static const uint8_t TCS34725_REG_ENABLE = 0x00;
static const uint8_t TCS34725_REG_ATIME = 0x01;
static const uint8_t TCS34725_REG_CONTROL = 0x0F;
static const uint8_t TCS34725_REG_STATUS = 0x13;
static const uint8_t TCS34725_REG_CDATAL = 0x14;
static const uint8_t TCS34725_ENABLE_PON = 0x01;
static const uint8_t TCS34725_ENABLE_AEN = 0x02;
static const uint8_t TCS34725_STATUS_AVALID = 0x01;
static const uint16_t COLOR_READ_INTERVAL_MS = 30;
static const uint16_t COLOR_I2C_TIMEOUT_MS = 50;

static volatile bool g_streamClientActive = false;
static uint8_t* g_streamJpegBuffer = nullptr;
static uint8_t* g_streamFrameLatest = nullptr;
static uint8_t* g_streamFrameWork = nullptr;
static uint8_t* g_streamFrameTx = nullptr;
static size_t g_streamFrameLatestLen = 0;
static uint32_t g_streamFrameSeq = 0;
static SemaphoreHandle_t g_streamFrameMutex = nullptr;
static TaskHandle_t g_streamCaptureTaskHandle = nullptr;

static bool g_colorReady = false;
static uint16_t g_colorClear = 0;
static uint16_t g_colorRed = 0;
static uint16_t g_colorGreen = 0;
static uint16_t g_colorBlue = 0;
static uint32_t g_lastColorReadMs = 0;
static const char* g_colorName = "unknown";

static camera_config_t camera_config = {
    .pin_pwdn      = PWDN_GPIO_NUM,
    .pin_reset     = RESET_GPIO_NUM,
    .pin_xclk      = XCLK_GPIO_NUM,
    .pin_sscb_sda  = SIOD_GPIO_NUM,
    .pin_sscb_scl  = SIOC_GPIO_NUM,
    .pin_d7        = Y9_GPIO_NUM,
    .pin_d6        = Y8_GPIO_NUM,
    .pin_d5        = Y7_GPIO_NUM,
    .pin_d4        = Y6_GPIO_NUM,
    .pin_d3        = Y5_GPIO_NUM,
    .pin_d2        = Y4_GPIO_NUM,
    .pin_d1        = Y3_GPIO_NUM,
    .pin_d0        = Y2_GPIO_NUM,
    .pin_vsync     = VSYNC_GPIO_NUM,
    .pin_href      = HREF_GPIO_NUM,
    .pin_pclk      = PCLK_GPIO_NUM,

    .xclk_freq_hz  = 20000000,
    .ledc_timer    = LEDC_TIMER_0,
    .ledc_channel  = LEDC_CHANNEL_0,

    .pixel_format  = PIXFORMAT_RGB565,
    .frame_size    = STREAM_FRAME_SIZE,
    .jpeg_quality  = 12,
    .fb_count      = 2,
    .fb_location   = CAMERA_FB_IN_PSRAM,
    .grab_mode     = CAMERA_GRAB_LATEST,
    .sccb_i2c_port = 0,
};

static void tuneCamera() {
    sensor_t* s = esp_camera_sensor_get();
    if (!s) return;

    s->set_framesize(s, STREAM_FRAME_SIZE);

    const uint16_t pid = s->id.PID;
    Serial.printf("Sensor PID: 0x%04X\n", pid);

    if (pid == GC0308_PID) {
        // GC0308 uses sensor-specific semantics for "contrast" and "gain_ctrl".
        // Force sane defaults and then apply a mild low-light boost.
        s->set_reg(s, 0xfe, 0xFF, 0x00); // page 0
        s->set_reg(s, 0xb3, 0xFF, 0x40); // neutral contrast (default)
        s->set_reg(s, 0x50, 0xFF, 0x28); // global gain (default 0x14)
        return;
    }

    // Generic profile for sensors that support these controls.
    s->set_brightness(s, 1);
    s->set_contrast(s, 0);
    s->set_saturation(s, 0);
    s->set_sharpness(s, 0);
    s->set_denoise(s, 1);
    s->set_whitebal(s, 1);
    s->set_awb_gain(s, 1);
    s->set_exposure_ctrl(s, 1);
    s->set_aec2(s, 1);
    s->set_ae_level(s, 1);
    s->set_gain_ctrl(s, 1);
    s->set_agc_gain(s, 20);
    s->set_quality(s, 10);
}

static bool writeClientFully(WiFiClient& client, const uint8_t* data, size_t len) {
    size_t sent = 0;
    while (sent < len && client.connected()) {
        size_t chunk = min((size_t)STREAM_CHUNK_BYTES, len - sent);
        size_t written = client.write(data + sent, chunk);
        if (written == 0) {
            return false;
        }
        sent += written;
    }
    return sent == len;
}

struct JpegClientContext {
    WiFiClient* client;
    uint8_t* buffer;
    size_t capacity;
    size_t buffered;
    bool ok;
};

static size_t jpgWriteToClient(void* arg, size_t index, const void* data, size_t len) {
    (void)index;

    JpegClientContext* ctx = static_cast<JpegClientContext*>(arg);
    if (!ctx || !ctx->client || !ctx->ok || !ctx->client->connected() || !ctx->buffer || ctx->capacity == 0) {
        if (ctx) {
            ctx->ok = false;
        }
        return 0;
    }

    const uint8_t* src = static_cast<const uint8_t*>(data);
    size_t remaining = len;
    while (remaining > 0 && ctx->ok) {
        size_t room = ctx->capacity - ctx->buffered;
        if (room == 0) {
            if (!writeClientFully(*ctx->client, ctx->buffer, ctx->buffered)) {
                ctx->ok = false;
                break;
            }
            ctx->buffered = 0;
            room = ctx->capacity;
        }
        size_t chunk = min(room, remaining);
        memcpy(ctx->buffer + ctx->buffered, src, chunk);
        ctx->buffered += chunk;
        src += chunk;
        remaining -= chunk;
    }

    return len - remaining;
}

struct FrameEncodeContext {
    uint8_t* buffer;
    size_t capacity;
    size_t len;
    bool ok;
};
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

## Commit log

2026-04-11 Defence 1
    [BOM.csv, http_latency_2026-04-11_18-28-33.csv, http_latency_2026-04-11_19-34-31.csv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]
2026-04-14 Printable model
    [chassis_n20.scad, chassis_n20_printable.scad, chassis_n20_printable.stl]
2026-04-14 Printable fix
    [chassis_n20.scad, chassis_n20_printable. small.stl, chassis_n20_printable.stl]
2026-05-01 Laser implementation
2026-06-17 Reorganize project structure and restore test results
    [3D_1-PCB_PCB_ATOM_SUMO_2026-04-14.f3d, 3rdfloor.f3d, Assembly new.f3z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]
2026-06-17 Finalize Verstapost evidence and test analysis
    [BOM.csv, VERSTAPOST_REQUIREMENTS_TRACKER.xlsx, auto_behavior_operator_observation.csv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]
